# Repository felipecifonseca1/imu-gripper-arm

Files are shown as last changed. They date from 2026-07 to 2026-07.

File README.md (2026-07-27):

# IMU-Controlled Gripper Arm

An ESP32-based robotic gripper arm that uses a **BNO085 9-DOF IMU** for real-time attitude estimation and maps the resulting orientation angles (roll, pitch, yaw) to three servo motors (gripper, elevation, yaw ).

Built with [PlatformIO](https://platformio.org/) and the Arduino framework.

---

## Repository Structure

```
imu-gripper-arm/
├── include/              # Global project headers
│   └── config.h          # Calibration matrices, magnetic references, filter thresholds
│
├── src/                  # Application entry points
│   └── main.cpp              # Full arm control (IMU → attitude → 3 servos)
│
├── lib/                  # Project-local libraries
│   ├── IMUSensor/            # Hardware abstraction layer
│   │   ├── IMUSensor.h           # Abstract IMU interface (accel, gyro, mag)
│   │   ├── BNO085_HAL.h/.cpp     # Concrete BNO085 driver (I²C, SH-2 reports)
│   │
│   ├── AttitudeEstimator/    # Sensor fusion / orientation estimation
│   │   ├── AttitudeEstimator.h/.cpp  # Strategy manager
│   │   ├── MadgwickFilter.h/.cpp     # Madgwick gradient-descent AHRS (not used in the project)
│   │   ├── MahonyFilter.h/.cpp       # Mahony complementary AHRS (not used in the project)
│   │   ├── ESKFFilter.h/.cpp         # Error-State Kalman Filter (used in the project)
│   │   ├── MEKF.h/.cpp              # Multiplicative Extended Kalman Filter (not used in the project)
│   │   └── NoneFilter.h/.cpp        # Pass-through (raw quaternion from accel+mag) (not used in the project)
│   │
│   ├── SensorCalibration/    # Offline calibration routines
│   │   ├── SensorCalibration.h/.cpp  # Ellipsoid fit, static offset, noise variance,
│   │                                 # Allan variance collection, tumble calibration
│   │
│   └── ServoController/      # Servo output stage
│       ├── ServoController.h/.cpp    # LPF smoothing, deadband, slew-rate limiting,
│                                     # IMU-to-servo angle mapping
│
├── scripts/              # Python helper scripts (host-side)
│   ├── collect_serial.py         # Collects raw gyro data over serial → CSV
│   └── analyze_allan_variance.py # Allan deviation analysis & plotting
│
├── platformio.ini        # Build environment & dependencies
├── teleplot_full.json    # Teleplot layout for real-time serial plotting visualization 
├── .gitignore
└── README.md            
```

---

## Build & Upload

The project compiles the `full_arm` target by default.

Build & upload:

```bash
pio run -t upload
pio device monitor          # 115200 baud
```

---

## Hardware

| Component | Details |
|---|---|
| **MCU** | ESP32 DevKit V1 |
| **IMU** | BNO085 (I²C, SDA 21 / SCL 22) |
| **Servos** | 3× PWM servos — Gripper (GPIO 32), Elevation (GPIO 33), Yaw (GPIO 27) |

---

## Libraries & Dependencies

### PlatformIO 
- `Adafruit BNO08x` — SH-2 sensor hub driver
- `ArduinoEigen` — Eigen linear algebra (used in Kalman filters & calibration)
- `ESP32Servo` — Hardware PWM servo control

### Project-local (`lib/`)

| Library | What it does |
|---|---|
| **IMUSensor** | Abstract sensor interface + BNO085 concrete driver |
| **AttitudeEstimator** | Strategy-pattern filter manager with 5 interchangeable filters (Madgwick, Mahony, ESKF, MEKF, None) |
| **SensorCalibration** | Ellipsoid-fit (accel/mag), static zero-rate offset (gyro), noise variance estimation, Allan variance data collection, tumble calibration |
| **ServoController** | Maps IMU angles to servo PWM with configurable LPF, deadband, slew-rate limiting, and input range mapping |

> [!NOTE]
> **Component Origin & Attribution:**
> - **`IMUSensor`**: Base sensor abstraction interface was imported from a previous project. The BNO085 driver was adapted from the Adafruit BNO08x library and developed for this project.
> - **`AttitudeEstimator`**: Estimator framework and baseline orientation filters (`MadgwickFilter`, `MahonyFilter`, `MEKF`, `NoneFilter`) were imported from a previous project. The **`ESKFFilter`** (Error-State Kalman Filter) was developed specifically for this project.

---

## Attitude Filters

Select a filter in code via:

```cpp
estimator.selectFilter(AttitudeFilterSel::ESKF);
```

| Filter | Description |
|---|---|
| `NONE` | Direct quaternion from accelerometer + magnetometer (no gyro fusion) |
| `MADGWICK` | Gradient-descent complementary filter |
| `MAHONY` | Proportional-integral complementary filter |
| `ESKF` | Error-State Kalman Filter (quaternion error-state, full 9-DOF) |
| `MEKF` | Multiplicative Extended Kalman Filter |

---

## Calibration Workflow

1. **Static calibration** — keep the sensor still to estimate gyro zero-rate offsets and noise variances
2. **Dynamic calibration** — rotate the sensor in all directions for accelerometer/magnetometer ellipsoid fit
3. **Tumble calibration** — multi-position static poses via serial prompt for high-precision accel/mag calibration
4. **Allan variance** — long-duration (e.g. 30 min) stationary recording for gyro noise characterisation

Results (offsets & gain matrices) are stored in [`include/config.h`](include/config.h).

### Python Scripts

```bash
# Collect raw gyro data over serial
python scripts/collect_serial.py --port COM3 --baud 115200 --out allan_data.csv

# Compute & plot Allan deviation
python scripts/analyze_allan_variance.py --csv allan_data.csv --rate 100
```

Requires: `pyserial`, `pandas`, `numpy`, `matplotlib`, `allantools`

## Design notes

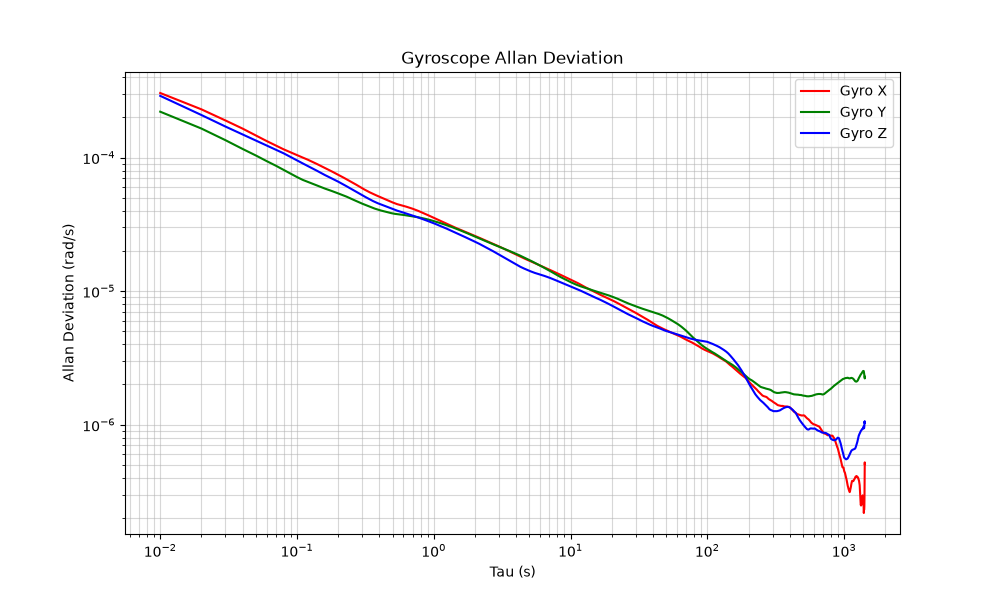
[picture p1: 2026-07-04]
my_data.png

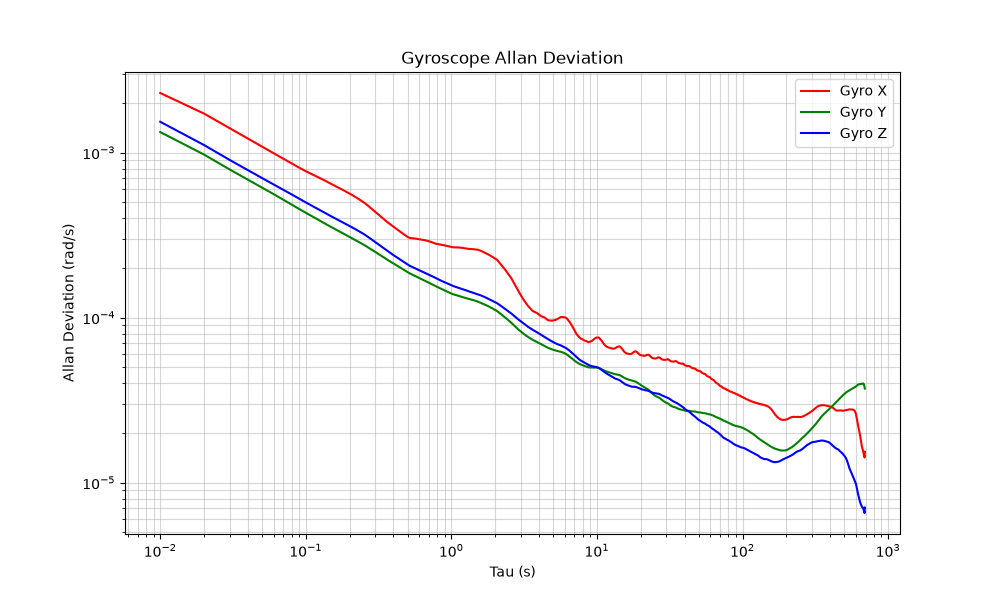
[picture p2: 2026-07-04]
raw_data.png

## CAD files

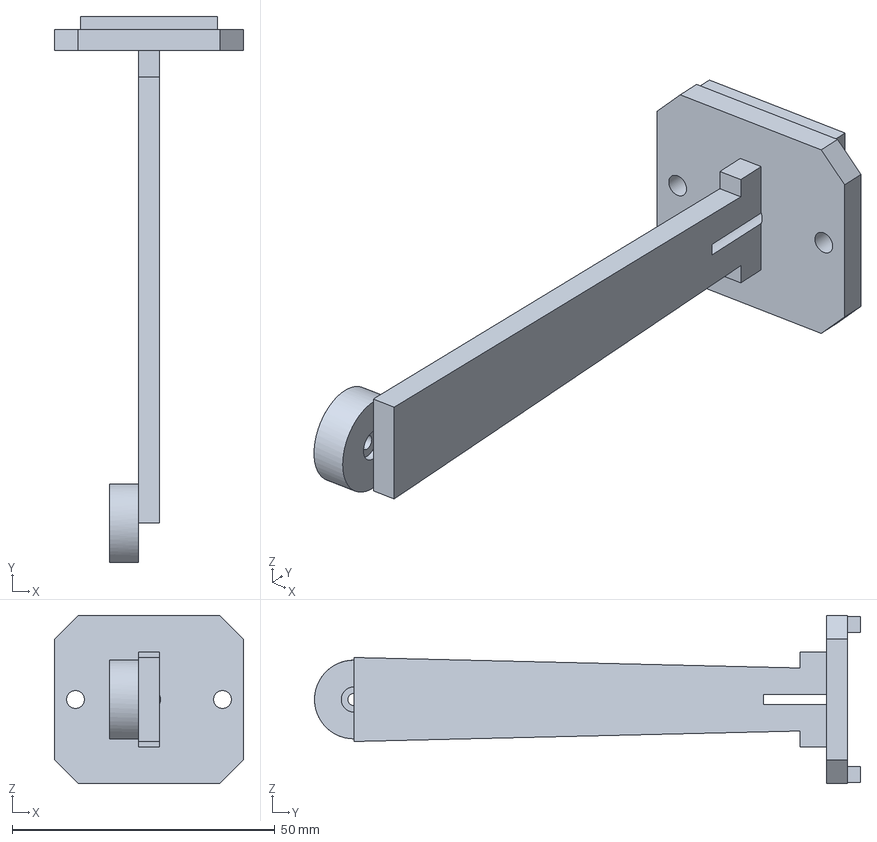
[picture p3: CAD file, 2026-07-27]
CADFiles/pitch_hebel.step
36.0 x 104.0 x 32.0 mm

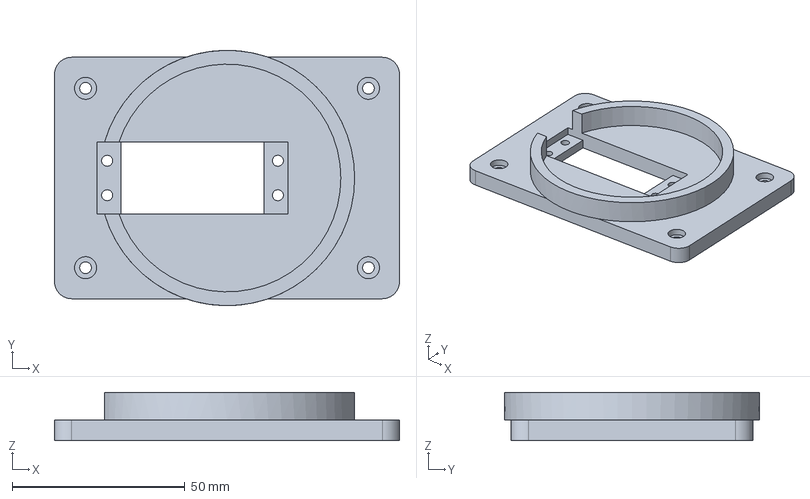
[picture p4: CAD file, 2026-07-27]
CADFiles/deckplatte_ring.step
100.0 x 74.0 x 14.0 mm

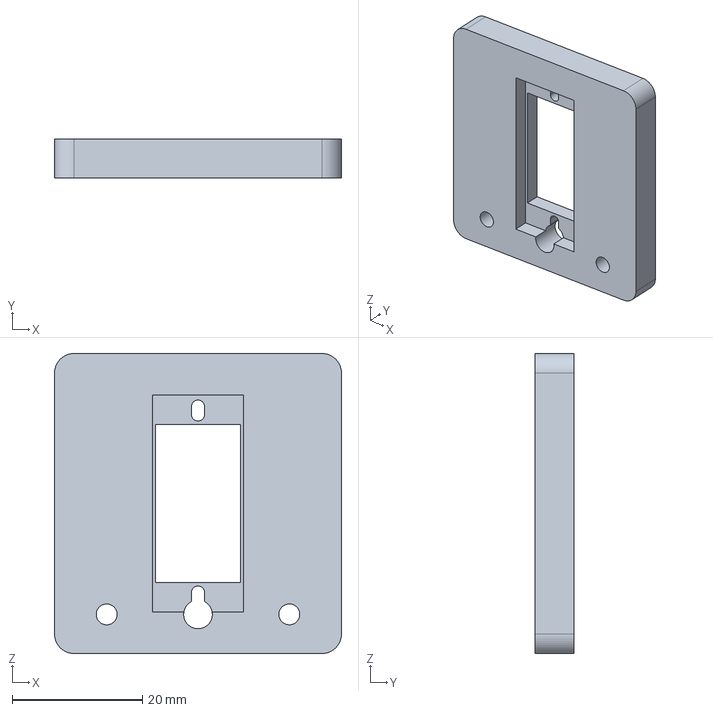
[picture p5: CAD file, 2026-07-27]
CADFiles/gripper_base_plate_reely.step
44.0 x 6.00 x 46.0 mm

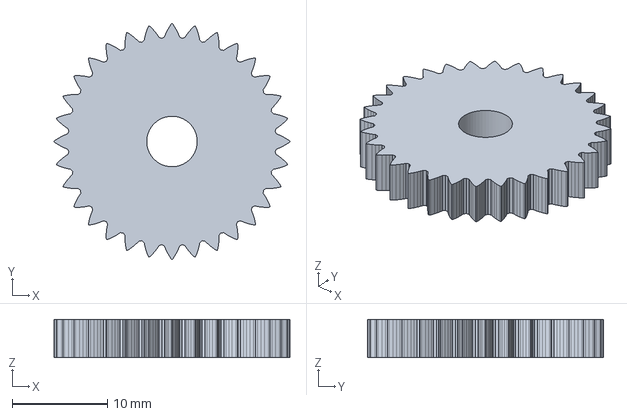
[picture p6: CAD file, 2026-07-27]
CADFiles/gear_right_shift.step
24.8 x 24.8 x 4.00 mm

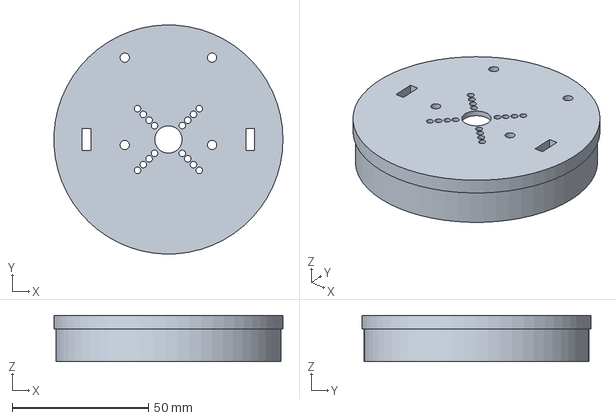
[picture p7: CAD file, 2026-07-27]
CADFiles/drehteller.step
83.9 x 84.0 x 17.0 mm

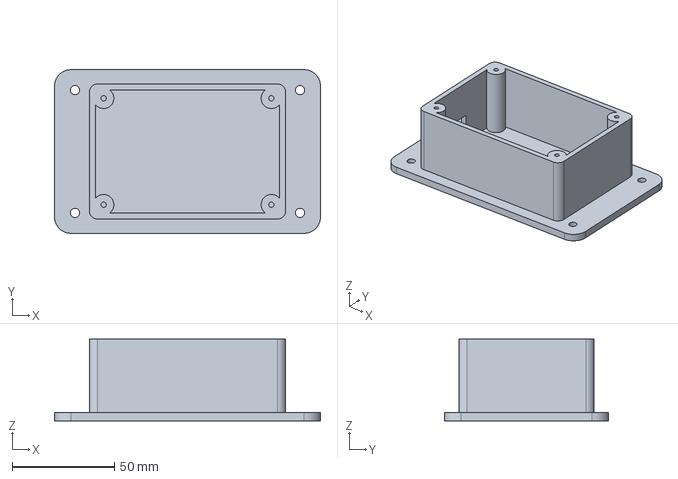
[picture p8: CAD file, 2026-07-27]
CADFiles/wanne.step
130.0 x 80.0 x 40.0 mm

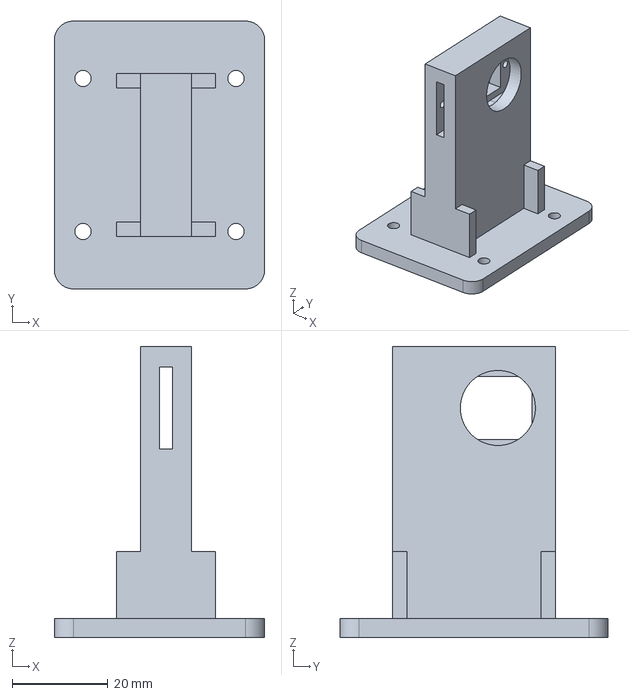
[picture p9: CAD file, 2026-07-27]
CADFiles/pitch_halter.step
44.0 x 56.0 x 60.9 mm

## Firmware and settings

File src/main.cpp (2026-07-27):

#include <Arduino.h>
#include <Wire.h>
#include "BNO085_HAL.h"
#include "AttitudeEstimator.h"
#include "SensorCalibration.h"
#include "config.h"
#include "ServoController.h"

// --- Pin Definitions ---
#define I2C_SDA 21
#define I2C_SCL 22
#define BNO08X_INT 34 // Hardware Interrupt Pin
#define GRIPPER_PIN 32 
#define ELEVATION_PIN 33
#define YAW_PIN 27

// --- Hardware Instances ---
BNO085_HAL imu;
AttitudeEstimator estimator(&imu);
ServoController servoController;

// --- Timing Variables ---
unsigned long lastPrintTime = 0;
unsigned long sampleCount = 0;
unsigned long lastSampleTime = 0;

// --- Performance Evaluation Metrics ---
unsigned long maxUpdateMicros = 0;   // Tracks worst-case execution spike
float avgUpdateMicros = 0.0f;        // Running Exponential Moving Average (EMA)
const float EMA_ALPHA = 0.01f;       // Smoothing weight factor (looks at last ~100 samples)

// --- Gripper Toggle State ---
bool gripperOverride = false;        // true = spacebar controls gripper, false = IMU controls
bool gripperOpen = true;             // toggle state: true = open (90°), false = closed (0°)

/**
 * @brief Forward declaration of the timing stress test function.
 */
void runFilterSpeedStressTest();

/**
 * @brief Arduino setup routine initializing serial, I2C IMU hardware, orientation estimator, and servos.
 */
void setup() {
    Serial.begin(115200);
    unsigned long startWait = millis();
    while (!Serial && millis() - startWait < 3000) delay(10); // Wait max 3 seconds for Serial Monitor
    
    Serial.println("\n--- BNO085 Hardware Verification Test ---");
    Wire.begin(I2C_SDA, I2C_SCL);
    Wire.setTimeOut(200);
    Wire.setClock(100000);     // 100kHz Fast-mode I2C for reduced bus latency
    if (!imu.init(true, false)) {
        Serial.println("ERROR: Failed to initialize BNO085!");
        while (1) { delay(10); }
    }
    Serial.println("BNO085 Initialized Successfully!");

    estimator.selectFilter(AttitudeFilterSel::ESKF);
    estimator.setUseMagnetometer(true);
    estimator.setMagneticLocation(MagLocation::MUNICH);

    // --- Run Isolated Computational Stress Test ---
    // runFilterSpeedStressTest();
    // SensorCalibration::runDynamicCalibration(&imu); // Fast Accel/Mag scale and offsets (Rotate sensor)
    // SensorCalibration::runTumbleCalibration(&imu);  // High-Precision Accel/Mag (Static poses via Serial 's')
    // SensorCalibration::runStaticCalibration(&imu);  // For Gyro offset and Noise variances (Keep still)
    // SensorCalibration::runAllanVarianceCollection(&imu, 1800000); // 30min test at 100Hz

    servoController.init(GRIPPER_PIN, ELEVATION_PIN, YAW_PIN);
    // Continuous noise threshold 
    servoController.setDeadbands(2.0f, 1.0f, 1.5f);
    // Smooth LPF alpha parameters 
    servoController.setFilterAlphas(0.2f, 0.1f, 0.2f);
    // Slew rate limiting (max 120 deg/s for mechanical stability)
    servoController.setSlewRateLimits(120.0f, 120.0f, 150.0f);
    // Physical IMU input range configuration
    servoController.setRollRange(-30.0f, 0.0f);    // Gripper: -30 deg IMU = closed (0 deg), 0 deg IMU = open (90 deg)
    servoController.setPitchRange(-90.0f, 90.0f);  // Elevation: ±90 deg IMU -> 0 to 180 deg Servo
    servoController.setYawRange(-45.0f, 45.0f);     // Yaw: ±45 deg IMU -> 0 to 180 deg Servo
    
    Serial.println("\n--- Setup Complete ---");
    Serial.println("Send 'roll,pitch' for manual override. Press SPACE to toggle gripper open/closed.");

    lastSampleTime = micros();
}

/**
 * @brief Arduino main execution loop processing serial input, IMU updates, servo control, and telemetry output.
 */
void loop() {
    // --- 1. Read from USB Serial Monitor ---
    if (Serial.available()) {
        String rawInput = Serial.readStringUntil('\n');
        rawInput.trim();

        // "roll,pitch": Manual servo override
        if (rawInput.length() > 0) {
            int commaIndex = rawInput.indexOf(',');
            if (commaIndex > 0) {
                float targetRoll = rawInput.substring(0, commaIndex).toFloat();
                float targetPitch = rawInput.substring(commaIndex + 1).toFloat();
                Serial.printf("Test Input -> Target Roll: %.2f | Target Pitch: %.2f\n", targetRoll, targetPitch);
                // Set override state directly without blocking delay loops
                gripperOverride = true;
                gripperOpen = (targetRoll > -15.0f);
            }
        }
    }

    // --- 2. Poll hardware and update IMU ---
    if (imu.update()) {
        unsigned long currentMicros = micros();
        float dt = (currentMicros - lastSampleTime) / 1000000.0f;
        lastSampleTime = currentMicros;

        unsigned long startCompute = micros();
        estimator.update(dt, false);
        unsigned long endCompute = micros();

        unsigned long currentUpdateMicros = endCompute - startCompute;
        
        if (currentUpdateMicros > maxUpdateMicros) {
            maxUpdateMicros = currentUpdateMicros;
        }

        if (avgUpdateMicros == 0.0f) {
            avgUpdateMicros = (float)currentUpdateMicros;
        } else {
            avgUpdateMicros = (EMA_ALPHA * currentUpdateMicros) + ((1.0f - EMA_ALPHA) * avgUpdateMicros);
        }
    }

    // --- 3. Decoupled 50Hz Servo Execution Loop (Independent of IMU poll timing) ---
    static unsigned long lastServoUpdate = 0;
    if (millis() - lastServoUpdate >= 20) {
        lastServoUpdate = millis();

        float roll = estimator.getRoll();
        float pitch = estimator.getPitch();
        float yaw = estimator.getYaw();

        if (gripperOverride) {
            roll = gripperOpen ? 0.0f : -30.0f;
        }

        servoController.update(roll, pitch, yaw);
    }

    // --- 4. Print debug data every 50ms ---
    if (millis() - lastPrintTime >= 50) {
        lastPrintTime = millis();
        // Standard format for Serial Monitor
        Serial.printf("Target [Roll: %5.1f | Pitch: %5.1f | Yaw: %5.1f] ---> Servos [Gripper: %3d | Elevation: %3d | Yaw: %3d]\n",
                      estimator.getRoll(), estimator.getPitch(), estimator.getYaw(),
                      servoController.getGripperAngle(), servoController.getElevationAngle(), servoController.getYawAngle());
        // Teleplot format for plotting
        // Serial.printf(
        //         ">Roll:%f\n>Pitch:%f\n>Yaw:%f\n"
        //         ">ax:%f\n>ay:%f\n>az:%f\n"
        //         ">gx:%f\n>gy:%f\n>gz:%f\n"
        //         ">mx:%f\n>my:%f\n>mz:%f\n",
        //         estimator.getRoll(), estimator.getPitch(), estimator.getYaw(),
        //         estimator.getTransformedAccX(), estimator.getTransformedAccY(), estimator.getTransformedAccZ(),
        //         estimator.getTransformedGyroX(), estimator.getTransformedGyroY(), estimator.getTransformedGyroZ(),
        //         estimator.getTransformedMagX(), estimator.getTransformedMagY(), estimator.getTransformedMagZ()
        //     );
    }
}

/**
 * @brief Executes isolated computational speed stress test over 1,000 iterations.
 */
void runFilterSpeedStressTest() {
    Serial.println("\n=====================================================");
    Serial.println("  RUNNING FILTER COMPUTATIONAL SPEED STRESS TEST     ");
    Serial.println("=====================================================");
    Serial.println("Executing 1,000 baseline updates over static cache...");
    delay(500); // Allow serial buffer to settle

    const int iterations = 1000;
    const float simulated_dt = 0.01f; // Fixed 100Hz step simulation
    
    unsigned long startTest = micros();
    for (int i = 0; i < iterations; i++) {
        estimator.update(simulated_dt, false);
    }
    unsigned long endTest = micros();
    
    unsigned long totalTimeMicros = endTest - startTest;
    float averageCallMicros = (float)totalTimeMicros / (float)iterations;

    Serial.printf(">> Test Completed for %d Iterations.\n", iterations);
    Serial.printf(">> Total Computation Duration : %lu us\n", totalTimeMicros);
    Serial.printf(">> Isolated Pure Filter Cost  : %.3f us per call\n", averageCallMicros);
    Serial.println("=====================================================\n");
}

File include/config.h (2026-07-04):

#ifndef CONFIG_H
#define CONFIG_H

#include <stdint.h>

enum class MagLocation : uint8_t {
    SAO_PAULO,
    PIRASSUNUNGA,
    MUNICH,
    MIDLAND_TX
};

constexpr MagLocation DEFAULT_MAG_LOCATION = MagLocation::MUNICH;
constexpr float ORIENTATION_MASK_MAX_G = 1.5f;
constexpr float ORIENTATION_MASK_MIN_G = 0.5f;
constexpr float ATTITUDE_GYRO_CUTOFF_DPS = 0.2f;
constexpr float NET_ACC_THRESHOLD = 0.15f;

// --- Calibration Matrices (Default to Identity / Zero) ---
constexpr float ACCEL_OFFSET[3] = {-0.014878f, 0.022074f, -0.025961f};
constexpr float ACCEL_GAIN[9] = {1.037306f, 0.000000f, 0.000000f, 0.000000f, 0.998076f, 0.000000f, 0.000000f, 0.000000f, 0.985926f};

constexpr float GYRO_OFFSET[3] = {0.000803f, -0.002635f, -0.002316f};
constexpr float GYRO_GAIN[9]    = {1.0f, 0.0f, 0.0f, 0.0f, 1.0f, 0.0f, 0.0f, 0.0f, 1.0f};

constexpr float MAG_OFFSET[3] = {3.890188f, -4.042345f, 1.342559f};
constexpr float MAG_GAIN[9] = {0.027269f, 0.000000f, 0.000000f, 0.000000f, 0.017655f, 0.000000f, 0.000000f, 0.000000f, 0.019616f};
#endif // CONFIG_H

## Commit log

2026-07-03 feat(imu): add BNO085 HAL and integrate attitude estimation infrastructure
    - Implement BNO085_HAL wrapper conforming to IMUSensor interface
    - Integrate existing AttitudeEstimator library into workspace
    - Refactor main.cpp to utilize BNO085_HAL and implement debug printing
2026-07-03 feat(attitude): integrate ArduinoEigen and connect AttitudeEstimator to BNO085
    - Add ArduinoEigen to library dependencies in platformio.ini.
    - Update main.cpp to instantiate AttitudeEstimator using BNO085, select MEKF filter, and print Euler angles every 50ms.
    - Create include/config.h containing common estimator threshold constants and MagLocation enum.
    - Refactor AttitudeEstimator to include config.h, accept MagLocation enum, and align raw sensor magnetometer readings directly.
2026-07-03 feat(attitude-estimator): implement error-state kalman filter (eskf)
    - Implement state propagation, Jacobian computation, Kalman gain, correction, and covariance propagation in ESKFFilter.
    - Resolve circular dependency and macro collisions with Arduino headers.
2026-07-03 feat(estimator): update ESKF noise parameters and add calibration script
    - Integrate measured accelerometer, gyroscope, and magnetometer noise variances into ESKFFilter
    - Modify main.cpp to print raw sensor values in CSV format for calibration
    - Add scripts/estimate_noise.py to estimate sensor noise density over serial
    - Remove Python template code from T6_template_code
    [main.cpp]
2026-07-03 feat(calib): add onboard sensor calibration library and integrate offsets
    - Implement SVD ellipsoid fit, static ZRO, and noise estimation in SensorCalibration.
    - Add runDynamicCalibration, runTumbleCalibration, and runStaticCalibration workflows.
    - Apply gain and offset transformations in AttitudeEstimator::update.
    - Remove deprecated PC-side scripts/estimate_noise.py.
    [config.h, main.cpp]
2026-07-03 fix(calibration): resolve printf format specifier and clean includes
    - Update format specifier from %d to %zu in SensorCalibration::runTumbleCalibration for size_t argument.
    - Remove unused <vector> and SensorCalibration.h headers from main.cpp.
    [main.cpp]
2026-07-03 feat(calibration): implement time-window averaging and update sensor parameters
    - Implement 50Hz time-window averaging in dynamic calibration to filter noise and prevent heap exhaustion.
    - Update config.h with calibrated offset and gain matrices for accel, gyro, and magnetometer.
    - Switch active filter to ESKF in main.cpp.
    [config.h, main.cpp]
2026-07-03 fix(estimator): resolve ESKF divergence, math sign errors, and coordinate transpositions
    - Correct row vs column indexing (transpose operations) in ecompass, rotMatToGravity, and rotMatToMagnetic to match world_from_body coordinate frames.
    - Scale reference gravity to 1.0g to align with raw sensor units.
    - Implement dynamic magnetic reference projection to decouple magnetometer updates from roll/pitch estimations.
    - Correct sign of nominal state updates by adding rather than subtracting error state corrections.
    - Add missing linear acceleration Jacobian block in measurement matrix H_k.
    - Switch flight controller initialization in main.cpp to utilize ESKF.
    [main.cpp]
2026-07-03 feat(main): optimize and format serial prints for Teleplot live telemetry
    - Consolidate raw data and Euler angle prints into a single Serial.printf call to minimize lock overhead and context switching.
    - Format variables using the Teleplot protocol (>varName:value) for real-time visualization.
2026-07-04 chore(calibration): update IMU offsets, ESKF noise parameters, and gitignore
    - Update static `GYRO_OFFSET` values in `include/config.h` with newly characterized zero-rate bias profiles.
    - Adjust measurement noise covariance parameters in `ESKFFilter.cpp` to reflect empirical sensor variance:
    - Increase `AccelerometerNoise` from 2.6198e-06f to 3.2393e-04f.
    - Increase `GyroscopeNoise` from 7.8677e-07f to 2.9105e-06f.
    - Append `.venv/*` to `.gitignore` to exclude local Python virtual environments from version control.
    [analyze_allan_variance.py, collect_serial.py, config.h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]
2026-07-09 fix(mekf): apply optimizations to the filter
2026-07-09 feat(servo): integrate 3-axis servo control with IMU data stream
    - Unified `src/main.cpp` to drive servo controller directly from IMU estimator
    - Expanded `ServoController` to support a third Yaw servo (pin 19)
    - Implemented angle getters and `ESP32Servo` dependency
    - Added Teleplot support for virtual servo angles (Servo1-3)
    - Removed redundant `src/base/main.cpp` file
2026-07-22 Add servo smoothing, deadbands and new hardware mapping
2026-07-22 docs(comments): add Doxygen comments for function signatures across codebase
    Complete missing @brief, @param, and @return documentation blocks for sensor drivers, calibration routines, orientation filters, servo controller, and main application setup.
    [main.cpp]
2026-07-27 Clean up platformio.ini by removing unused environments
    Removed multiple environment configurations for single servo, calibration, and servo test.
2026-07-27 Add README.md for IMU-Controlled Gripper Arm
    Added detailed project documentation for the IMU-Controlled Gripper Arm, including repository structure, build instructions, hardware specifications, library dependencies, attitude filters, and calib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
2026-07-27 CAD Files
    [deckplatte_ring.step, drehteller.step, gear_right_shift.step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]
2026-07-27 Remove gripper toggle on space bar press
    Removed space bar toggle functionality for gripper.
2026-07-27 fix(arm): resolve serial parser syntax error, update telemetry & README attribution
    - Fix invalid control flow in src/main.cpp serial parser
    - Restore standard Serial Monitor telemetry output format
    - Add library attribution note in README.md for imported vs custom components
    - Clean unused MagLocation entries in config.h and comments in ESKFFilter
    [main.cpp]
